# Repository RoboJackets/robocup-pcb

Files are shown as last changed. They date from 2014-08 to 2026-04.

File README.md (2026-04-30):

RoboCup PCB Repository
===========
Welcome to the Georgia Tech RoboJackets repository for management and storage of RoboCup's hardware files! Additional information about the team and current projects can be found on the [RoboJackets Website](http://www.robojackets.org/teams/robocup/) and the [RoboJacket Wiki](http://wiki.robojackets.org/w/RoboCup).

If you are a new member to the RoboCup electrical team and have never used *[git version control](http://git-scm.com/)* before, we highly recommend that you familiarize yourself with it by reading [this guide](https://git-scm.com/book/en/v2).

## Prerequisites
- A computer configured with git [[Linux (Preferred)](https://git-scm.com/install/linux)] [[Windows](https://windows.github.com)] [[Mac](https://mac.github.com/)]
- An installation of [KiCAD v10.0](http://kicad-pcb.org/download/)

## Setup

### Cloning the Repository
To clone the repository, run the following command in your terminal:
```
git clone git@github.com:RoboJackets/robocup-pcb.git
```

## Board Archives
All currently deployed boards as of 2026 were designed using KiCAD.

However, older boards in the archives were designed using [EAGLE](http://www.cadsoftusa.com/) or [PCB](http://pcb.geda-project.org) (a program that is part of the [gEDA project](http://www.geda-project.org))

Unfortunately, EAGLE and PCB are no longer supported by their respective companies, and are not available for download. If you need access to these files, you are on your own.

## License

This project is licensed under the Apache License v2.0.  See the [LICENSE](LICENSE) file for more information.

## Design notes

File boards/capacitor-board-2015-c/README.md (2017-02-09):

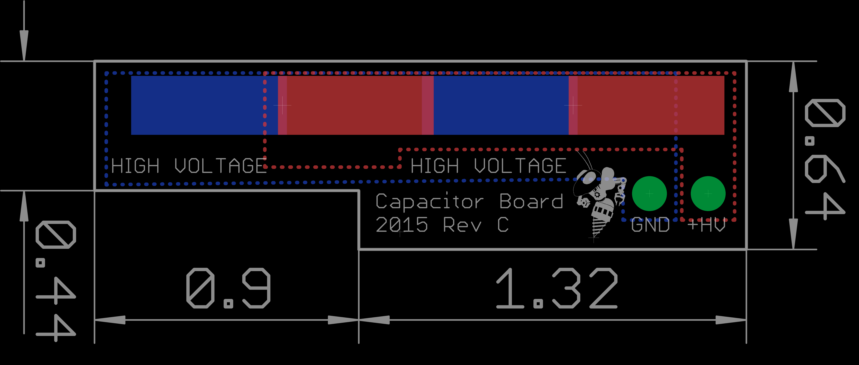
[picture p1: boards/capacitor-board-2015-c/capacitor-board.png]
Capacitor Board


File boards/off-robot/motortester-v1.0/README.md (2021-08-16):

# MotorTester Board
Off Robot Board

# Objective 
Simulate a 3 Phase Brushless Motor to connect to the control board, allowing us to test the motor functionality without blowing the motor. 

# Details 
- ATMega writes Hall sensor values (H1, H2, and H3) to the control board, which in turn responds with the proper voltages to the motor tester.  
- Voltages provided by the control board, either high (~18V), low (~0V) or float(somewhere in between), are stepped down by way of a voltage divider and the divided voltage is read in by the ATMega.  
- For each voltage, the ATMega checks to verify that it is correct, whether high, low, or float, for the given hall sensors, as given for the following table. 
 
## Hall Value/Voltage Level: 
001:10/  
101:1/0  
100:/10  
110:01/  
010:0/1  
011:/01  
These comparisons are made, and the LCD screen tells us if the motor is being supplied appropriately, to ensure it won't be blown.  

## PNG 
motortester

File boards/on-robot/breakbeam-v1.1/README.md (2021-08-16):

# Breakbeam Board
On Robot Board 

## Objective 
To indicate whether ball has been successfully captured by robot 

## Approach 
Infrared beam exists across the robot's mouth. Board detects whether the beam is broken by ball passing through it. Interfaces with kicker board. 

## PNG 
breakbeam

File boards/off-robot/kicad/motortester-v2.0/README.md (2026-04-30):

# Motor Tester Board v2.0

This board serves as a proof of concept (PoC) for the design of control board v4.0

## Components

The main components contained in this board are:

- Xilinx Spartan 7 25T FPGA
- QSPI Flash Memory
- CMOS Clock
- USB/JTAG/UART Interface
- 18.5V, 5V, 3.3V, 1.8V, 1.0V Voltage Levels
- 3 Phase Motor Driver

### FPGA

This is the main controller that coordinates the 5 different motor drivers.
It interfaces the main microcontroller via SPI and controls the 3 phase gate drivers.

The CMOS clock is connected directly to the FPGA as the sys_clk.

### QSPI Flash Memory

Non-volatile memory to store the config files for the FPGA. FPGA should be bootable from flash on reset.

### USB Interface

Allows to program the FPGA and QSPI Flash without the need of a debug probe. This is done using Xilinv Vivado.

### Voltage Levels

The FPGA board allows for different voltage levels on each IO Bank.

- The FPGA logic fabric uses 1.0V
- IOBANKs use 3.3V

Aside from the FPGA, the motor drivers require direct battery voltage, 18.5V (nominal) for the
motor current, and 5V to operate the gate driver IC.

The microcontroller also requires a 5V supply to be powered.

### Motor Driver

This is a 3 Phase BLDC motor driver.
(I'll list down the specifics of this later).

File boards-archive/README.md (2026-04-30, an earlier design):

# Boards Archive

A large reorganization of this repository was performed in early 2026. All such boards live (mostly unorganized) in the `pre-2026` directory. All other boards are organized by design revision (e.g. `rev-2027`).

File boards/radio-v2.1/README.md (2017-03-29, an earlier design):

# Radio Board

Board containing radio circuitry to communicate between robot(s) and base station

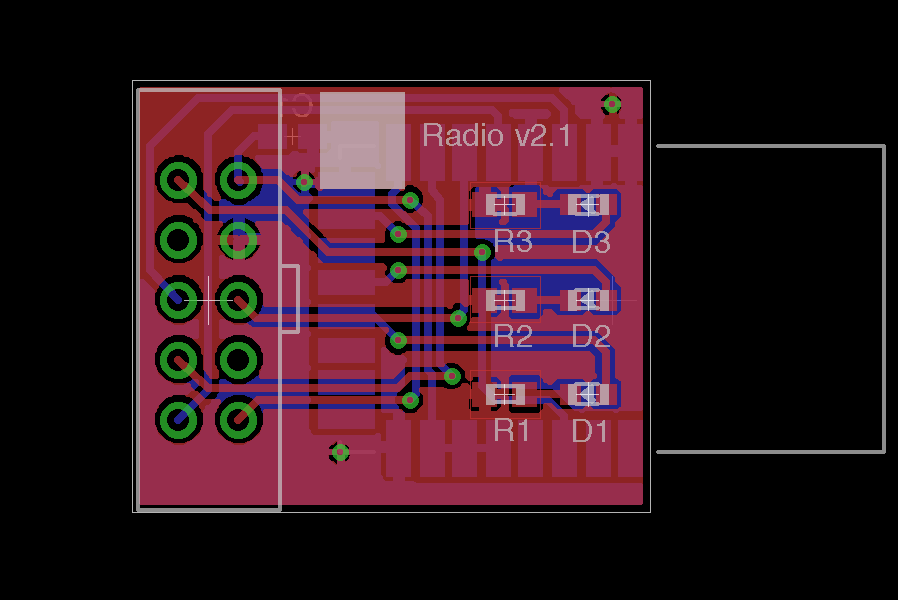
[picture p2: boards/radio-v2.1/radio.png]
Radio Board


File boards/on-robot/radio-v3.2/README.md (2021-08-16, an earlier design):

# Radio Board
On Robot Board 

# Objective
Uses onboard bluetooth/wifi module to communicate with other robots. Most radio logic is handled on the chip. 

# Approach 
- Radio outputs are delivered to the connector, which allows the robot to interface with this board.  
- Radio is supplied by a 3.3V source. DC-DC converter is used to step down the 5V supply on the board to the needed 3.3V volts, and keep power supply stable.  
- RF components are very sensitive, ESD protection chips are needed to prevent damaging components with any built up static.  
- The radio firmware may need updates. In event of update, there is a JTAG programming port.  

## PNG 
radio

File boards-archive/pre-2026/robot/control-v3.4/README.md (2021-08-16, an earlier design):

# Control Board
On Robot Board 

## Objective 
Regulates voltages, connects mTrain to other boards, user interface, hardware to enable motor control 

## Specifics of v3.4
IR connector, extra SPI connector, many improvements to be made

## Approach 
 - MTrain is our microcontroller, has three SPI buses which tie it to the FPGA, the radio, and then all other devices. 
 - AnalogIn is used to monitor battery voltage and input voltage  
 - Reset network reset MTrain if the 3.3V is low and the MTrain is high  
 - IO expander connects hex pins and DIP switches to MTrain for inputs into MTrain
 - FPGA handles all of the wheel drivers and the dribble driver, including the SPI interface to those motor drivers (AUX)
 - Handles hall sensors and writing three phase motor states.

- The battery provides 18.5V, so the voltage regulation circuits also produce other voltage levels (5V and 3.3V) that other devices run off.
- 18.5V is only needed for the motors.  
- There are also 1.2V and 2.5V lines, and when these are out of tolerance, error LEDs are activated

- Wheel Drive Module writes each of the three phases for the motor. Takes inputs of whether phase should be high and low, and uses outputs to write each phase
- Phase is set that it can be high (shorted to 18V) low (shorted to ground) or float (some indeterminate phase in between).
- Dribbler Drive Module works in similar approach

## Control board has connectors for all of the different modules on the board, including:
- IMU  
- Kicker  
- Radio  
- Ball Speed (IR)  
- I2C Module  
The SPI interfaces for each of these connectors is supplied by the MTrain and monitored by the Dot Star network

## PNG 
control

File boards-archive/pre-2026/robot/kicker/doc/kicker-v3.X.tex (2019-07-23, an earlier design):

\documentclass[12pt, letterpaper]{article}
\usepackage[utf8]{inputenc}
 
\title{RoboJackets RoboCup Kicker v3.0}
\author{William Stuckey \thanks{I'd like to acknowledge Ryo Osawa and Jon Jones for their patient mentorship in helping a CS major through the world of analog and digital electronics for the first time.}}
\date{August 2018}
 
\begin{document}
 
\begin{titlepage}
\maketitle
\end{titlepage}

\section{Preface}

I want to write this document to address the recurring pattern of shoddy RoboCup kicker boards. Electrical Engineers with practical experience are pretty hard to come by, especially early in their undergraduate careers. For many kicker boards designers, this is their first time doing \"serious and practical\" EE work (myself included). A lot of past mistakes are undocumented or have been ignored. Over the past month I've looked at every kicker revision since 2013 and talked to past members in an attempt to understand common mistakes. \textbf{Future kicker board designers should start here.} At least that is my hope.

\section{Introduction}

In RoboCup SSL, ground kicks (referred to as kicks) and chip kicks (referred to as chips) are critical robot functions. In order to get precise control over kick speed, the league has largely standardized on using elctromagnetic solenoids to kick and chip balls. By varying the amount of time current flows through the solenoid, software can control how hard the ball is kicked. 

In order to support this system of ball control, the robot needs a subsystem to drive these solenoids. The subsystem in contained on the kicker board, a PCB dedicated to this task. The highest level functional overview contains three main systems: 1) a charging system to convert low voltage DC to high voltage DC that charges a capacitor bank; 2) a discharge system to release the energy stored in the capacitor bank through the solenoids, thus kicking the ball; 3) a control system to regulate charge and discharge cycles accurately and safely. Subsystems for v3.0 are described in detail below as subsections under \"Kicker v3.0\".

Driving a solenoid with sufficient force has proven to be a non-trivial task for the following reasons: 1) modeling the solenoid impedance over time is difficult because mesauring the magnetic field is difficult; 2) modeling energy transfer to the mechanical system is difficult to measure; 3) high voltages and currents are involved making some mistakes far more fatal than digital designers are used to. Points 1 and 2 result in a lot of design iteration based on testing and high-level data gathering rather than theory. The third point results in usually ignorable issues, no longer being ignorable. This includes noise, ringing, and transient voltage spikes. As well, FET and diode ratings have added complexity in voltage ratings and swithing times. Read data sheets for AC subsystem components carefully. 

As a final note, the energy stored in the capacitor bank is non-trivial. It can and will shock you, and under very ideal conditions is potentially dangerous. Just be careful when handling these boards.

\section{Past Results}
Past kicker board designs have had mixed success in terms of safety and reliability. A short list of results is below:

\subsection{Kicker 2013}
We don't have a lot of surviving experiential notes and docs from the 2013 era. The boards weren't radcally different. They had a smaller storage capacity and less debugging information. We've also been handed down the criticisms that they didn't like the choice of IGBTs over power FETs for discharge because the switching times would be too high if they ever wanted to PWM control the solenoids. The cost was also higher. 

Some older designs also use two stacked IGBTs/FETs to achieve a high current rating. The failure rate was too high due to swithing time variances from (relatively) imprecise binning. 

\subsection{Kicker 2015 (v1.X)}
The 2015 kicker suffered from two fatal issues. The first issue was the gate voltage rating of AC system switching fet. The gate was only rated for 20V and was driven directly from the battery. While a 5 cell LiPo has a nominal voltage below 20V, at max charge and no load the LiPo will have a voltage of about 21V. Over time this damaged FET gates and caused the HVAC system to fail.

Additionally, the microcontroller used to regulate chrage and discharge cycles was located too far to close to the HVAC transformer. The interference prevented communication between the microcontroller and the surrounding components rendering it useless. We had to tap the relevant lines with wire and assert control signals from elsewhere in 2015. This impacted performance.

\subsection{Kicker 2017 (v2.X)}
The 2017 kicker design addressed issues from the 2015 design. 

Initially the 2017 design had a misspeced rectifer diode on the HVAC system. The Trr (reverse recovery time) was too long, causing almost all of the energy to be attenuated by the diode or reflected back to the switching FET. This was further complicated by the fact that the diodes varied greatly in binning. Some well binned diodes had an acceptable Trr which result in it taking over a year to identify the issue. Once the part was speced correctly the charging system worked very well.

Early on we had difficulty kicking at low speeds because of generated interference. We determined the cause of the issue was the presence of TVS diodes on the discharge FETs. They were originally intended to prevent the 21V max battery from damaging a 20V rated gate, but the breakdown threshold and parasitic capcitance resulted in oscillation that rapidly switched the discharge FET on and off generating massive amounts of high frewuency interference. This caused microcontroller reboots and corrupted data on the global SPI line resulting in radio brownouts. This was not truely fixed on 2017, instead the TVS diodes were simply removed at the 21V rarely damaged the power FETs. In v3.0, a 15.0V LDO is used to drive the FETs rather than direct batter voltage. The 20V TVS diodes remain in the design to protect the FETs against ringing and trasient spikes. 

Another minor issue observed under unclear condtions was the presence of ringing on the HVAC regulator IC control lines. It was difficult to assertain the magnitude of the issue, as the parasitic inductance and capcaitance of scope probes amplified the problem. As a precaution, snubbers with a cutoff frequency of 1kHz have been added to all HVAC regulator IC control lines. These are some of the longest traces on the board and the only digitial IO lines that are required to pass by the HVAC system.

The last minor issue observed was inconsistency in HV charge time and level holding. The deathlight, intended to indicate if there is power on the HV rail leaked too much current. We think replacing this with a microcontroller controlled level indiciator is an acceptable trade off. It now requires the microcontroller to function to report voltage on the line. Our operating assumption is that if it's too broken to report voltage level it's also too broken to flag a charge cycle. When unplugged, the auto discharge light will come one and it's approximate margnitude of brightness will indicate remainig charge ensuring that in virtually any case where the HV rail is powered, some safety indicator will be on. The leakage through the microcontroller should now be ones to tens of microamps rather than tens of miliamps. The inconsistency is auto-discharge time and cutoff was also likely a binning issue. We are reducing the tolerance when practical to 1\% or 0.1\% to address these issues.  

The biggest area for improvement on 2017 was the HV leakage issue and charge time. Most boards still took 2.5-3.5+ seconds to charge make our repetitive kick rate low. We are attempting to boost the charge rate in v3.0 to around half second. 

\section{Kicker v3.X}  
Kicker v3.0 began design in summer of 2018. As of now, it is under design review. The following seubsections are intended to be highly techinical, describing why parts were speced the way they were and what higher level considerations were included. 

\subsection{Overview}

\subsection{Input Power}
The input power section is responsible for generating the necessary sources of power for the board. It also includes protected. In this kicker board we need 4 voltages: raw battery, 15V, 5V, and HV. The source of HV has a dedicated section below called High Voltage Charging.

\subsubsection{Changes in v3.X}
A few changes were made to the input power subsystem. First, the surface mount fuse was replaced with a socketed fuse. This board will likely be able to charge at a very high rate and surface mount fuses become impractical at 50A. It may also be required to lower the charging current so easily swapping the fuse is good.

A new feature is the addition of reverse polarity pretection. This is done with a PFET right after the fuse. Although the input connector is polarity protected, in the past we've still managed to mess it up on occasion. When this happes 10 hours of labor and \$150 in parts are lost. Adding the protection is cheap and easy and will save time when accidents happen.

A new 15V rail was added to prevent overvoltages on discharge FET gates. The 15V rail is sourced from an adjustable LDO. 

TVS diodes were added to every power rail, except HV, to protect regulation and digital circuitry.

\subsection{Microcontroller}
The microcontroller is the primary logic for the kicker board. It communicates with the control board to report charge level, kick cycles status, readiness, and errors. It also has the critical function of translating a kick/chip strength into a time interval to control kick speed. It commands the charge and discharge states, ensure they've never occur at the same time. The microcontroller is also responsible for for handing breakbeam information.

\subsubsection{Changes in v3.0}
The microcontroller was upgraded from an ATTiny167 to an ATMega32. We wanted additional IO, timing features, and flash space. It's very similar to the 167 most ways just with an extra IO bank and flash. We considered switching to ARM, but liked that the 32 could be flashed from the same pins as it being a SPI slave, so we can flash and then communcate with the chip over the same SPI lines. It also meant we wouldn't have to rewrite significant chunks of the code base. The extra IO was used for error reporting.

$$ \omega_\mathrm{desired\_cutoff} \approx 10 kHz $$

\begin{equation} \label{eq:rc_snub}
\omega_\mathrm{cutoff} = 1 / (2 * \pi * R * C)
\end{equation}

$$ R_\mathrm{chosen} = 160 \Omega, C_\mathrm{chosen} = 0.1 \mu F $$

\begin{equation} \label{eq:rc_snub_situ}
\omega_\mathrm{cutoff} = 1 / (2 * \pi * 160 * 0.0000001) \approx 9947.18 Hz, \epsilon \approx 0.005
\end{equation}

RC snubbers were added to IO lines that pass by the HVAC system. This is included as a precaution based on past observed behavior that may case IO errors due to voltage spikes from interferences. These IO lines don't see high frequency switching so we can play pretty fast and loose on the snubber calibaration. We've picked an initial cutoff frequency of 10kHz. The cutoff frequency of an RC snubber can be calculated using the equation \ref{eq:rc_snub}. We selected resistor and capacitor values that can easily be acquired in E96 and the resulting cutoff frequency and error from desired can be seen in equation \ref{eq:rc_snub_situ}.

\subsection{High Voltage Charging}
The high voltage charging systems works by switching low voltage DC into low voltage AC. This low voltage AC becomes the primary side input to a transformer, that produces a higer voltage AC. We use a transformer with a turns ratio of 10:1, so we get a voltage approximately 10 times higher. The regulator actually produces a slightly higher voltage. The high voltage AC (HVAC) is then rectified by a diode in to high voltage DC to be store in the capacitors. 

Import considerations are the current ratings of the switching FET, transformer, and rectifier diode. The datasheet of you switching regulator IC can usually help you spec these components. For the diode, take extra caution to ensure the recovery times meet spec based on the swithing frequency of your regulator IC. For many ICs, that frequency is configurable.

\subsubsection{Changes in v3.0}
Significant changes were made to the HVAC system. The swithcing IC was changed from the LT3757 to the LT3751. The 3757 is a generic regulator, but the 3751 is specifically made for charging capacitor banks and other appllications that have periodic rather than coninuous charging cycles. Rather than enabling charging, a rising edge flags a charge cycle and the chip will carry out the cycle until a target voltage is reached or a fault occurs. The primary battery rail bypass capitance was increased to 1000uF of electrolytic and 30uF ceramic to accomodate the greater demands and interference of a 50A charging circuit. These values were recommended by the LT3751 datasheet.

The HVAC system has been updraded to support a primary current draw of 50A. The recitifier diode was respeced to have have a lower Trr and higher current (5A) to support faster charge times. The transformer was respeced from within the same product line as well. The DA203X series was replaced with the GA43XX series. The new transformer supports a maximum primary current of 50A rather than 10A. The turn ratio is unchanged at 10:1. The switching FET was already withing spec, and not changed. 

The capacitor bank was respeced as the old caps had been discontinued. We now have slightly larger (both physically and in capacitance) caps, bringing the total capacitance of the bank to 4000uF, a ~25\% increase.

The 5V swiitch mode regulator bypass caps were changed to better support how the global marked now produces ceramics. The pads were largened and duplicated to give the maximum flexibility in being able to source parts from the market.

\subsubsection{LT3751 Part Spec}
The HV\_AC regulator is the most complicated subsystem on the board and also one the hardest to debug. Rapid switching and high currents present a noise filled measurement challenge for most hobbiest equipment and complex analog interactions can make finidng the source of obvious failures hard. Subtle failures are even harder to debug because often times insturmentation is not recording when stochastic errors occur that wear down a part slowly over time. In order to help future designers, we are going to cover how we speced every part of the HV\_AC subsystem and what part attributes are the most important. If you haven't acquired a copy of the LT3751 datasheet, now would be the time to do so.

\paragraph{Voltage Protection Lockouts}

Before calibrating the voltage lockouts, we need to determine what an acceptable voltage range should be. In order to do this, we need to understand what the safe operating limits of our battery are and what other protection mechanisms we have put in place.

We define the acceptable LiPo cell voltage not underload as 

$$ 3.4 V < V_\mathrm{cell} < 4.2 V $$

and the acceptable minimum for a cell under load as

$$ V_\mathrm{cell\_load} \ge 3.1 V $$

Additionally we clamp $ V_\mathrm{batt} $ at 22.2V using a TVS diode.

With this information in hand, we can calculate our voltage lockouts from the following constraints

$$ N = 5, the number of cells $$
$$ V_\mathrm{cell\_abs\_min} = 3.1 V $$
$$ V_\mathrm{batt\_abs\_min} = N * V_\mathrm{cell\_abs\_min} = 5 * 3.1 V = 15.5 V $$
$$ V_\mathrm{batt\_abs\_max} = 23.5 V $$

\begin{equation} \label{eq:vbatt_range}
V_\mathrm{batt\_abs\_min} < V_\mathrm{batt} < V_\mathrm{batt\_abs\_max} \equiv 15.5 V < V_\mathrm{batt} < 23.5 V
\end{equation}

With the acceptable voltage range deifined, we can now calibrate our lockouts. Both Over Voltage and Under Voltage Lock Outs, OVLO and UVLO respectively, are defined by equation \ref{eq:lt_vlos}, which is arranged to provide the resistor value for convenience in equation \ref{eq:lt_vlos_arr}. 

\begin{equation} \label{eq:lt_vlos}
V_\mathrm{LO} = 1.225 + 0.50 \mu A * R_\mathrm{LO\_CALIB}
\end{equation}

\begin{equation} \label{eq:lt_vlos_arr}
R_\mathrm{LO\_CALIB} = (V_\mathrm{LO} - 1.225) / 0.5 \mu A
\end{equation}

Substituting the values from the range defined in equation \ref{eq:vbatt_range} into equation \ref{eq:lt_vlos_arr} yields the following resistor values:

$$ R_\mathrm{lvlo} = 285500 \approx 287k (E96) $$
$$ R_\mathrm{ovlo} = 445500 \approx 442k (E96) $$

\paragraph{High-Level Charding Characterization}

\subsection{High Voltage Discharging}

\subsubsection{Changes in v3.0}

\subsection{High Voltage Auto Safe Discharge}

\subsubsection{Changes in v3.0}

\subsection{Breakbeam}

\subsubsection{Changes in v3.0}

\subsection{Debugging and Status}

\subsubsection{Changes in v3.0}

\subsection{Errata}
None yet.

\end{document}

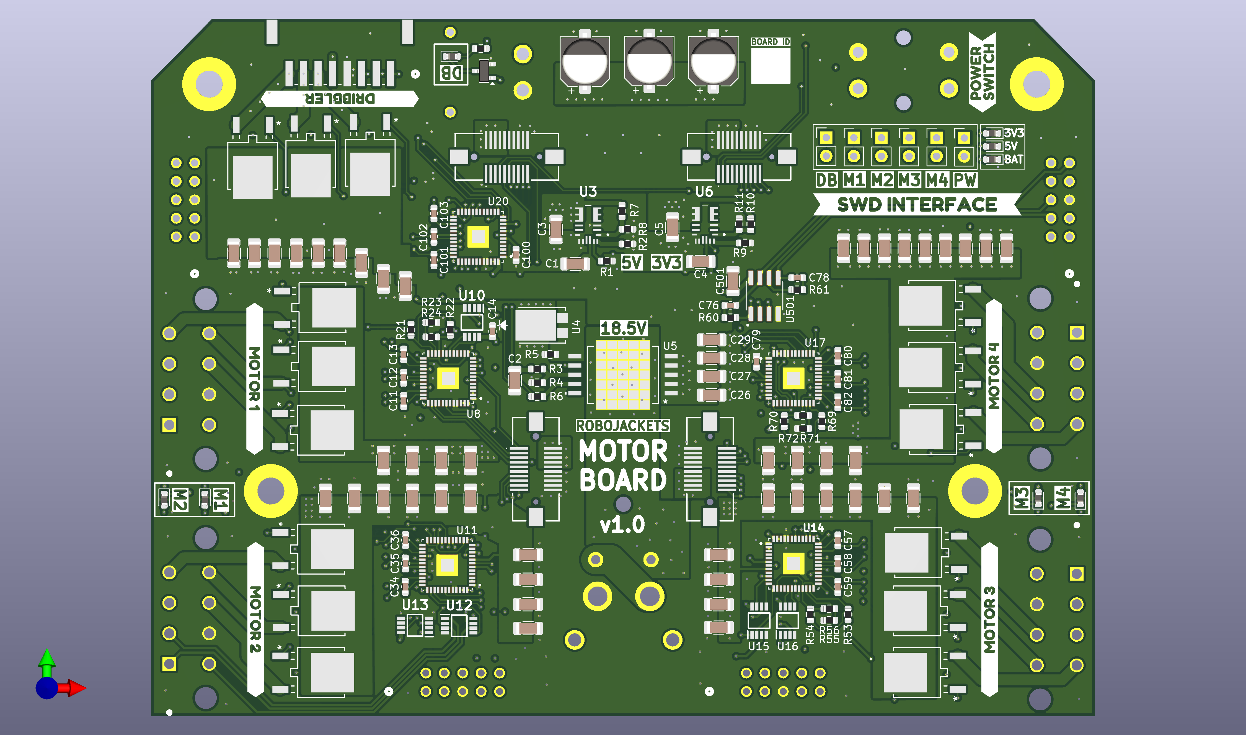
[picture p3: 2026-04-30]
boards/rev-2026/motorboard-v1.0/images/motorboard-modelpng.png

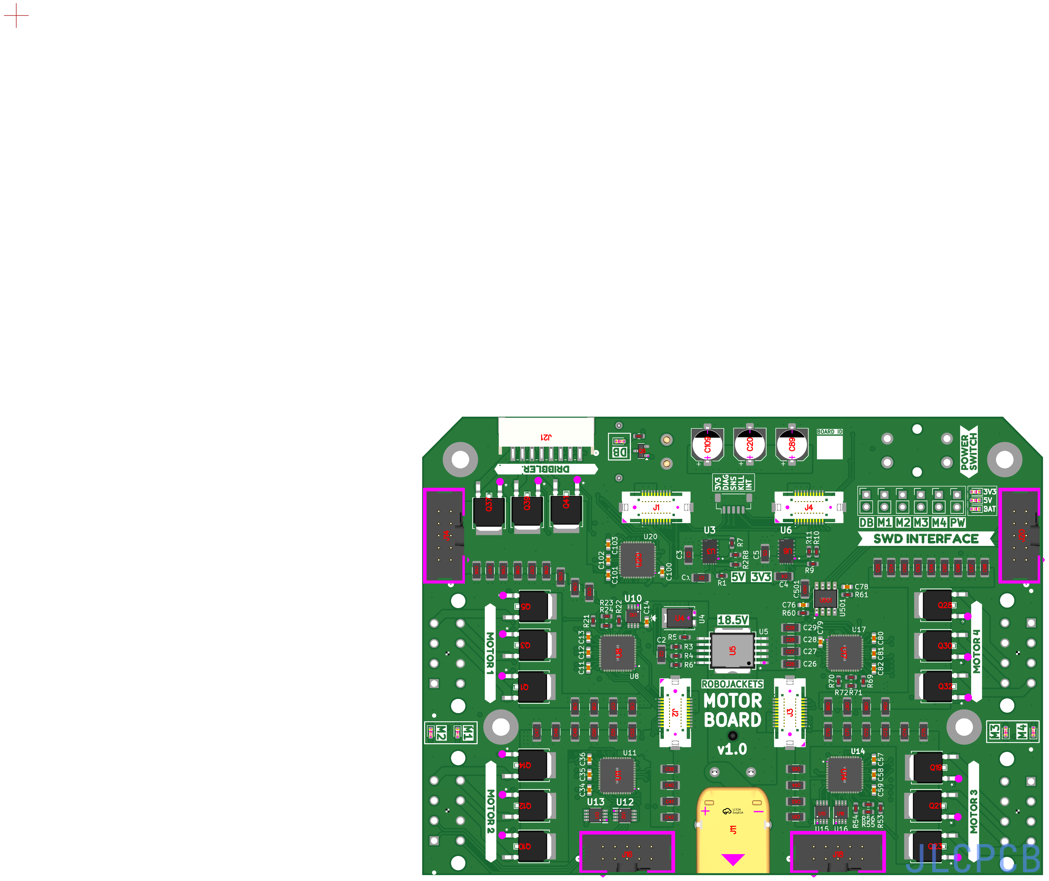
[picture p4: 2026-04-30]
boards/rev-2026/motorboard-v1.0/images/top_placement.png

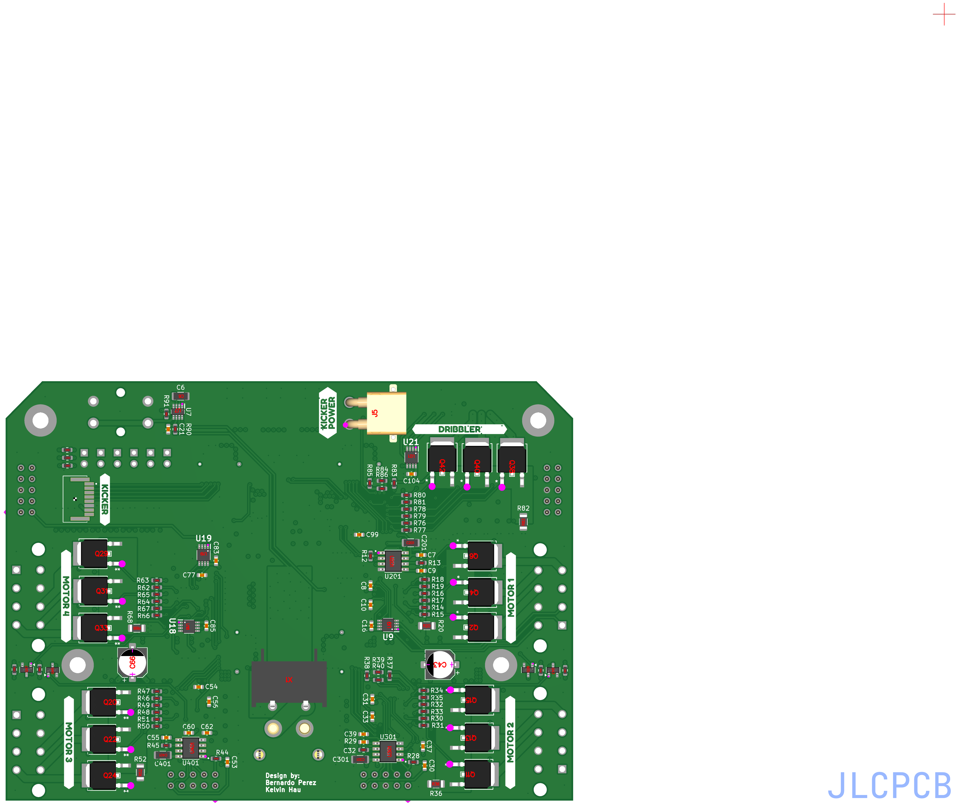
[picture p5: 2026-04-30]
boards/rev-2026/motorboard-v1.0/images/bottom_placement.png

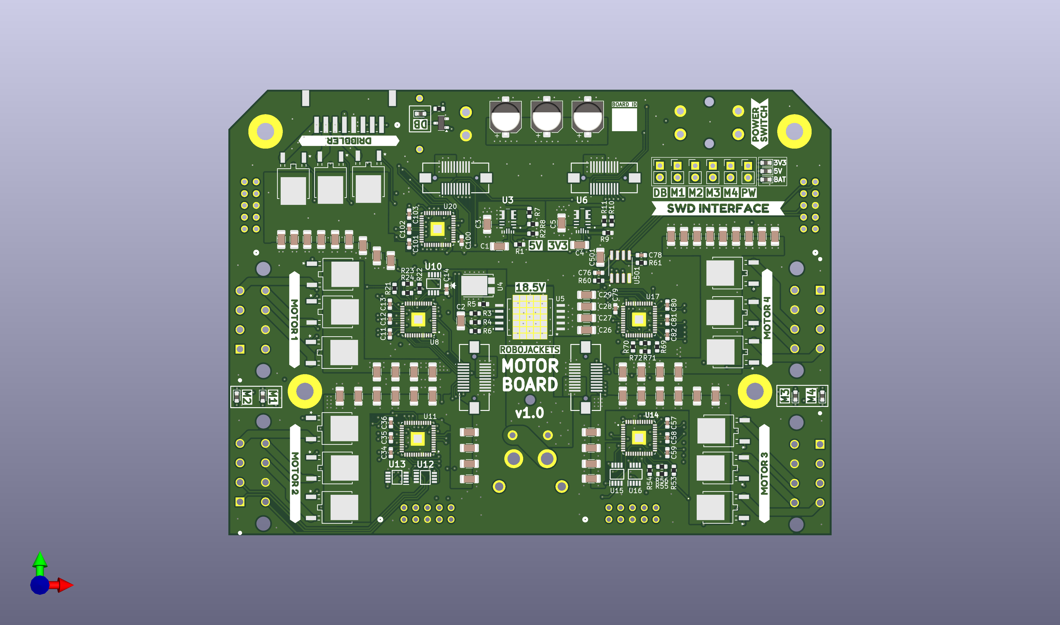
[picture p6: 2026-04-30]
boards/rev-2026/motorboard-v1.0/images/motorboard-model.png

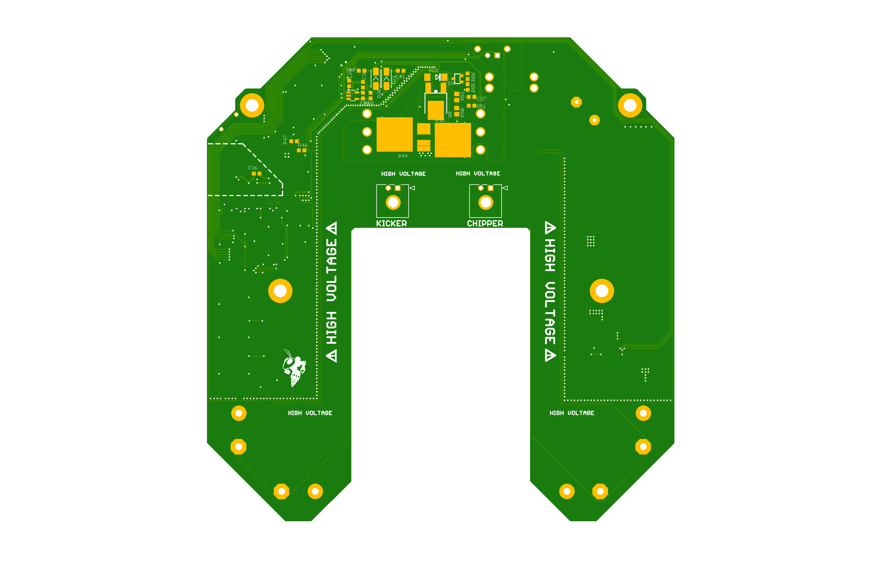
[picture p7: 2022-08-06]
boards/on-robot/kicker-4.0/kicker2.png

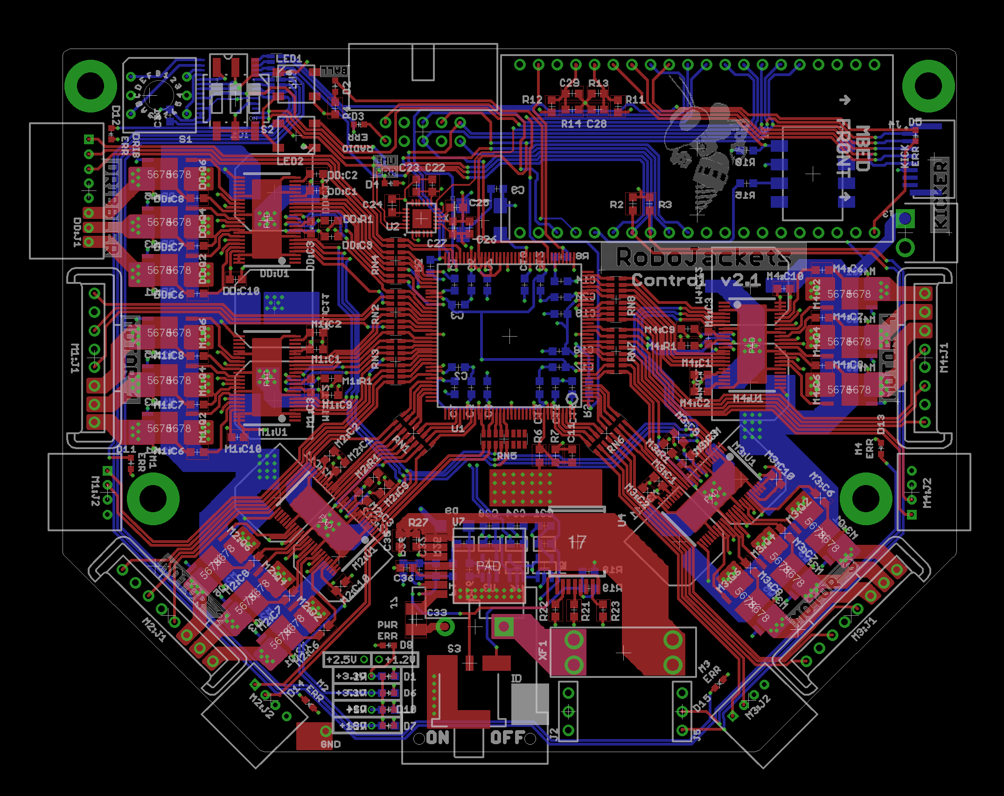
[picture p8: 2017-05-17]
boards/control-v2.1/control.png

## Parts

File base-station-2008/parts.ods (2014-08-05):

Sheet: Parts List
Type | Value | Package | Amount | P/N
SMD Resistor | 10 | R0603 | 2
SMD Resistor | 220 | R0603 | 5
SMD Cap | .1uF | C0603 | 2
SMD Cap | 10uf | PANASONIC_B | 1
SMD Cap | 10uf | C1206 | 1
SMD Cap | 1uF | C0603 | 5
SMD Resistor | 4.7k | R0603 | 1
SMD Cap | 47uF | PANASONIC_E | 1
Linear Vreg | 7805T | TO220H | 1 | LM7805CT
Microcontroller | ATMEGA169-16A | TQFP64 | 1 | ATMEGA169-16A | ATMEGA169V-8MU-ND | sample
LED |  | LED5MM | 5
Level Converter | MAX232-SO16 | SO16 | 1 | MAX232NSR | 296-15895-1-ND
Oscillator | 14.7456MHz | 7X5MM | 1 | CSX750FCC14.745600M-UT | 300-7209-1-ND | waiting
Ant. Conn |  | RPSMA_TH | 2
Receiver |  |  | 1 | RXM-900-HP3
Transmitter |  |  | 1 | TXM-900-HP3
Connector | JST_PA_2 | JST_PA_2 | 2
Connector | JST_PA_4 | JST_PA_4 | 1
SPI Conn | 2X05 | pinhead | 1

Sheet: Sheet1
Part | Value | Package | Library | Amount
R3 | 10 | R0603 | rcl
R4 | 10 | R0603 | rcl
R2 | 200 | R0603 | rcl
R5 | 200 | R0603 | rcl
R6 | 200 | R0603 | rcl
R7 | 200 | R0603 | rcl
R8 | 200 | R0603 | rcl
C3 | .1uFl | C0603 | rcl
C4 | 10uf | PANASONIC_B | rcl
C5 | 10uf | C1206 | rcl
C10 | 1uF | C0603 | rcl
C6 | 1uF | C0603 | rcl
C7 | 1uF | C0603 | rcl
C8 | 1uF | C0603 | rcl
C9 | 1uF | C0603 | rcl
JP1 | 2X05 | pinhead | (24.62
R1 | 4.7k | R0603 | rcl
C1 | 47uF | PANASONIC_E | rcl
IC2 | 7805T | TO220H | linear
IC3 | ATMEGA169-16A | TQFP64 | avr
C2 | C1206 | rcl | (65.95
U$1 | JST_PA_2 | JST_PA_2 | jst_pa
U$2 | JST_PA_2 | JST_PA_2 | jst_pa
U$8 | JST_PA_4 | JST_PA_4 | jst_pa
LED2 | LED5MM | led | (31.53
LED3 | LED5MM | led | (50.06
LED4 | LED5MM | led | (50.1
LED5 | LED5MM | led | (57.44
LED6 | LED5MM | led | (57.48
U$9 | MAX232-SO16 | SO16 | max232
U$3 | OSCILLATOR | 7X5MM | misc-personal
U$6 | RP_SMA_TH | RPSMA_TH | linx
U$7 | RP_SMA_TH | RPSMA_TH | linx
U$4 | RXM-900-HP3 | RXM-900-HP3 | HP3
U$5 | TXM-900-HP3 | TXM-900-HP3 | HP3

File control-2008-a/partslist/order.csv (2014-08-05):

Value | Device | Package | Count | Digikey # | Quant On Hand | Quant to Order | Notes
Green | LEDCHIP-LED0603 | CHIP-LED0603 | 2 | 160-1183-1-ND | 15 | 20
Yel |  |  | 2 | 160-1180-1-ND | 15 | 20
Red |  |  | 2 | 160-1182-1-ND | 15 | 20
 | JP2E | JP2 | 2 | S1012E-36-ND | 0 | 3
BAS16H | DIODE-SOD323-W | SOD323-W | 1 | BAS16HT1GOSCT-ND | 0 | 10 | Dboost
 | NMOSSOT23 | SOT-23 | 1 |  | 0 |  | Phillip's FET
0.01uF | C-USC0603 | C0603 | 6 | 399-1082-1-ND | 10 |  | 10000pf = .01uf
0.1uF | C-USC0603 | C0603 | 30 | 399-1100-1-ND | 500 | 0
10 | R-US_R0603 | R0603 | 2 | RHM10GCT-ND | 10
100pF | C-USC0603 | C0603 | 4 | 399-1061-1-ND | 10
10K | R-US_R0603 | R0603 | 2 | RHM10KGTR-ND | 10 |  | NOT ORDERED
10uF | C-USC1206 | C1206 | 3 | PCC2233CT-ND | 10
1K | R-US_R0603 | R0603 | 2 | RHM1.0KGCT-ND | 10
1uF | C-USC0603 | C0603 | 6 | PCC2399CT-ND | 0
220 | R-US_R0603 | R0603 | 48 | P220GCT-ND | 200
2M1-DP1-T1-B1-M2QE | 2M1-DP1-T1-B1-M2QE | 2M-DP-M2 | 1 | 432-1171-ND | 6 |  | Power switch
30.9K | R-US_R0603 | R0603 | 1 | 541-30.9KHCT-ND | 0
3522 | 3522 | 3522 | 2 | 3522K-ND | 0 |  | Fuseholders – 2 pcs
4.7K | R-US_R0603 | R0603 | 37 | RHM4.7KGCT-ND | 200
40K | R-US_R0603 | R0603 | 1 | RHM40.2KHCT-ND | 10
470 | R-US_R0603 | R0603 | 1 | RHM470GCT-ND | 0
470uF | CPOL-USE | PANASONIC_E | 16 | PCE3892CT-ND | 0
ADP1711-1.2 | ADP1711-1.2 | SOT23-5 | 1 | ADP1711AUJZ-1.2-R7CT-ND | 0 |  | 1V2 regulator
BAS16XV2 | BAS16XV2 | SOD-523 | 15 | BAS16XV2T1GOSCT-ND | 100 |  | Hall diodes
FH_11_H | FH_11_H | FH_11_HOR | 4 | HFB11CT-ND |  |  | Motor Connector
HP3_RX_SIP | HP3_RX_SIP | RX_DIP | 1 | RXM-900-HP3-PPS-ND |  |  | Do we want to order new modules?
HP3_TX_SIP | HP3_TX_SIP | TX_DIP | 1 | TXM-900-HP3-PPS-ND |  |  | Do we want to order new modules?
JST_PA_6 | JST_PA_6 | JST_PA_6 | 4 | 455-1821-ND | 10 |  | Header – actually only 4 per board (alt motors)
 |  |  | 4 | 455-1490-ND | 10 |  | Housing
JST_PA_8 | JST_PA_8 | JST_PA_8 | 2 | 455-1823-ND | 10 |  | Header
 |  |  | 2 | 455-1492-ND | 10 |  | Housing
 |  |  |  | 455-1325-1-ND | 100 |  | PA Pins
JST_VH_2 | JST_VH_2 | JST_VH_2 | 2 | 455-1639-ND | 20 |  | Header
 |  |  |  | 455-1183-ND | 20 |  | Housing
 |  |  |  | 455-1319-1-ND | 20 |  | VH Pins
LM2734Y | LM2734 | SOT23-6L | 1 | LM2734YMKCT-ND | 0
LP2985-18 | LP2985-18 | SOT23-5 | 1 | 296-18474-1-ND | 0
LP2985-25 | LP2985-25 | SOT23-5 | 1 | LP2985IM5-2.5CT-ND | 0
LPC2102 | LPC2102 | TQFP48 | 1 | 568-2094-ND | 0
MBR120LSF | DIODE-SOD123 | SOD123 | 2 | MBR120LSFT1GOSCT-ND | 0
MMBTA06LT1 | BC848 | SOT23 | 1 | MMBTA06LT1GOSCT-ND | 0
NTMS4503N | NTMS4503N | SO8 | 15 | IRF7805APBFCT-ND | 95 |  | NFET – IRF7805A
OSC | OSC | XTAL_LCC | 1 | 535-9311-1-ND | 0
PAN_EV_SWITCH | PAN_EV_SWITCH | PAN5 | 2 | P12240SCT-ND | 0
PS12 | PS12 | PS12 | 1 | 445-2525-1-ND | 6 |  | Buzzer
RP_SMA_TH | RP_SMA_TH | RPSMA_TH | 1 | CONREVSMA001-ND | 0
SWS004 | SWS004 | SMS-004 | 1 | CT2194MST-ND | 0 |  | Dip Switch
TC4428 | TC4428 | SO08 | 15 | TC4428COA-ND | 100
UPG2214 | UPG2214 | SMINI-6 | 1 | UPG2214TK-A-ND | 0
XC3S_TQ144 | XC3S_TQ144 | TQFP144 | 1 | 122-1478-ND | 0
 |  |  |  |  |  |  | Tweezers
 |  |  |  |  |  |  | Solder
M25P10 | M25P10 | SO08 | 1 | 511-M25P10-AVMN6P | 0 |  | FLASH – Mouser
NTMS10P02R2 | NTMS10P02R2 | SO8 | 15 | 512-FDS6673BZ | 35 |  | PFET – Mouser
MSS7341 | MSS7341 | MSS7341 | 1 |  | 10 |  | Sampled from coilcraft

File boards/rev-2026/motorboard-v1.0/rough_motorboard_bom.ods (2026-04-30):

Reference | Value | Datasheet | Footprint | Qty | DNP | Approx Unit Cost | Total Cost Per Board | Total Cost
C1,C2,C20,C31,C51,C52,C53,C54 | 0.1nF | ~ | Capacitor_SMD:C_0603_1608Metric | 8 |  | $0.40 | $3.20 | $32.00
C3,C6,C11,C13,C14,C15,C16,C17,C32,C34,C35,C36,C37,C38,C55,C57,C58,C59,C60,C61,C74,C76,C77,C78,C79,C80,C93,C95,C96,C97,C100 | 100nF | ~ | -- mixed values -- | 31 |  | $0.40 | $12.40 | $124.00
C4 | 400nF | ~ | Capacitor_SMD:C_1206_3216Metric | 1 |  | $0.40 | $0.40 | $4.00
C5 | 22nF | ~ | Capacitor_SMD:C_1206_3216Metric | 1 |  | $0.40 | $0.40 | $4.00
C7,C8,C18,C19,C21,C22,C23,C24,C25,C27,C29,C30,C39,C40,C41,C42,C45,C46,C47,C48,C49,C50,C62,C63,C64,C65,C68,C69,C70,C71,C72,C73,C81,C82,C83,C84,C87,C88,C89,C90,C91,C92,C99,C101,C102,C103,C106,C107,C108,C109,C110,C111 | 10uF | ~ | Capacitor_SMD:C_1206_3216Metric | 52 |  | $0.40 | $20.80 | $208.00
C9,C10 | 22uF | ~ | Capacitor_SMD:C_1206_3216Metric | 2 |  | $0.40 | $0.80 | $8.00
C12,C33,C56,C75,C94 | 1uF | ~ | Capacitor_SMD:C_0603_1608Metric | 5 |  | $0.40 | $2.00 | $20.00
C26,C28,C43,C44,C66,C67,C85,C86,C104,C105 | 220uF | ~ | Capacitor_THT:CP_Radial_D10.0mm_P5.00mm | 10 |  | $0.40 | $4.00 | $40.00
C98,C112,C113,C114,C115,C116,C117,C118,C119,C120 | 100n | ~ | Capacitor_SMD:C_1206_3216Metric | 10 |  | $0.40 | $4.00 | $40.00
D1,D2,D3,D4,D5,D6,D7,D8,D9,D10 | GREEN | ~ | Diode_SMD:D_0603_1608Metric | 10 |  | $0.20 | $2.00 | $20.00
F1 | Fuse | ~ |  | 1 |  | $0.30 | $0.30 | $3.00
J1 | XT60PW-M | https://www.tme.eu/Document/b13629717d44ae038681dba08d18c0b6/XT60PW-M.pdf | XT60PWM | 1 |  | $1.00 | $1.00 | $10.00
J2,J6,J10,J11,J14 | SWD | ~ | Connector_PinHeader_2.54mm:PinHeader_1x04_P2.54mm_Vertical | 5 |  | $1.00 | $5.00 | $50.00
J3,J4,J5,J7,J12 | 39301080 | 39301080 | RoboJackets-Connectors:CON_39301080 | 5 |  | $1.50 | $7.50 | $75.00
J8 | HFW8R-1STE1H1LF | https://cdn.amphenol-cs.com/media/wysiwyg/files/documentation/datasheet/flex/flexconnectors_100mm_hfw_r.pdf | RoboJackets-Connectors:AMPHENOL_HFW8R-1STE1H1LF | 1 |  | $0.30 | $0.30 | $3.00
J9 | XT60PW-F | https://www.tme.eu/Document/1191bc2fa3aee3c446e5a895fd8f7983/XT60PW-F.pdf | XT60PWF | 1 |  | $1.00 | $1.00 | $10.00
J13,J15 | Conn_01x12 | ~ |  | 2 |  | $0.50 | $1.00 | $10.00
J18,J19,J20,J21 | 52901-0274 | https://www.molex.com/pdm_docs/sd/529010274_sd.pdf | RoboJackets-Connectors:529010274 | 4 |  | $4.00 | $16.00 | $160.00
Q1,Q2,Q3,Q4,Q5,Q6,Q7,Q8,Q9,Q10,Q11,Q12,Q13,Q15,Q16,Q17,Q18,Q19,Q20,Q22,Q23,Q24,Q25,Q26,Q27,Q29,Q30,Q31,Q32,Q33 | STD140N6F7 | https://www.st.com/content/ccc/resource/technical/document/datasheet/group1/de/02/69/d9/32/b8/44/66/DM00257307/files/DM00257307.pdf/jcr:content/translations/e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 | DPAKTO-252_A2_STM | 30 |  | $2.00 | $60.00 | $600.00
Q14,Q21,Q28,Q34,Q? | BSS83P | http://www.farnell.com/datasheets/1835997.pdf | Package_TO_SOT_SMD:SOT-23 | 5 |  | $0.40 | $2.00 | $20.00
R1,R2,R28,R29,R42,R43,R44,R45 | 120 | ~ | Resistor_SMD:R_0603_1608Metric | 8 |  | $0.10 | $0.80 | $8.00
R3,R4,R5,R6,R7,R9,R24,R41,R57,R69,R81,R82,R83,R84,R85,R86,R87,R88,R89,R93,R94 | 10k | ~ | Resistor_SMD:R_0603_1608Metric | 21 |  | $0.10 | $2.10 | $21.00
R8,R22,R23,R39,R40,R55,R56,R67,R68,R79,R80 | 1k | ~ | Resistor_SMD:R_0603_1608Metric | 11 |  | $0.10 | $1.10 | $11.00
R10 | 43.2k | ~ | Resistor_SMD:R_0603_1608Metric | 1 |  | $0.10 | $0.10 | $1.00
R11 | 29.4k | ~ | Resistor_SMD:R_0603_1608Metric | 1 |  | $0.10 | $0.10 | $1.00
R12,R14 | 160k | ~ | Resistor_SMD:R_0603_1608Metric | 2 |  | $0.10 | $0.20 | $2.00
R13 | 30.1k | ~ | Resistor_SMD:R_0603_1608Metric | 1 |  | $0.10 | $0.10 | $1.00
R15,R16,R17,R18,R19,R20,R30,R31,R32,R33,R34,R35,R46,R47,R48,R49,R50,R51,R58,R59,R60,R61,R62,R63,R70,R71,R72,R73,R74,R75 | 62 | ~ | Resistor_SMD:R_0603_1608Metric | 30 |  | $0.10 | $3.00 | $30.00
R21,R26,R27,R36,R90 | 10m | ~ | Resistor_SMD:R_0603_1608Metric | 5 |  | $0.10 | $0.50 | $5.00
R25 | 51k | ~ | Resistor_SMD:R_0603_1608Metric | 1 |  | $0.10 | $0.10 | $1.00
R37,R38,R52,R53,R54,R64,R65,R66,R91,R92 | 1.6k | ~ | Resistor_SMD:R_0603_1608Metric | 10 |  | $0.10 | $1.00 | $10.00
SW1 | TL1105VF100Q | TL1105VF100Q | RoboJackets-Switches:SW_TL1105VF100Q_EWI | 1 |  | $0.40 | $0.40 | $4.00
SW2,SW3,SW4,SW5,SW6 | SW_SPDT | ~ | lib:Slide_Switch_SPDT | 5 |  | $0.40 | $2.00 | $20.00
U1,U12 | MC3486DR | https://www.ti.com/general/docs/suppproductinfo.tsp?distId=10 | lib:SOIC127P600X175-16N | 2 |  | $0.50 | $1.00 | $10.00
U2 | TPS1HTC30AQPWPRQ1 | https://www.ti.com/lit/gpn/tps1htc30-q1 | HTSSOP14_PWP_TEX | 1 |  | $5.00 | $5.00 | $50.00
U3 | LTC2955-1 | https://www.analog.com/media/en/technical-documentation/data-sheets/2955fa.pdf |  | 1 |  | $4.00 | $4.00 | $40.00
U4,U5 | MPM3620GQV-P | https://www.digikey.com/en/htmldatasheets/production/1785101/0/0/1/mpm3620-datasheet | QFN3p0x5p0x1p6_MPM3620_MNP | 2 |  | $2.00 | $4.00 | $40.00
U6,U9,U13,U16,U23 | STSPIN32F0A | https://www.st.com/resource/en/datasheet/stspin32f0.pdf | RoboJackets-IC:IC_STSPIN32F0A | 5 |  | $2.50 | $12.50 | $125.00
U7,U8,U10,U11,U14,U15,U17,U18,U25 | SN74LVC3G17DCTR | https://www.ti.com/lit/ds/symlink/sn74lvc3g17.pdf?ts=1726403224895 | DCT8 | 9 |  | $0.30 | $2.70 | $27.00
U19,U20,U21,U22 | 5102160-1 | https://www.te.com/commerce/DocumentDelivery/DDEController?Action=srchrtrv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 | RoboJackets-Connectors:TYCO_5102160-1 | 4 |  | $4.00 | $16.00 | $160.00
 |  |  |  |  |  |  |  | $2,008.00

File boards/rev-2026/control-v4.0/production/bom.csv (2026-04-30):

Designator | Footprint | Quantity | Value | LCSC Part #
BRD1 | Adafruit_SSD1306_No_Mounting_Holes | 1 | SSD1306
C1 | 0603 | 1 | 10uF
D1, D2 | 0603 | 2 | LED
J1, J2, J3, J4 | 536250274 | 4 | 53625-0274
R1, R2 | 0603 | 2 | 4.7K
R3, R4 | 0603 | 2 | 1K
S1 | HEX | 1 | 94HCB16T
U1 | nRF24L01_Breakout | 1 | NRF24L01_Breakout
U2 | HeaderIMUFooter | 1 | IMU Header
U3 | Teensy41 | 1 | Teensy4.1

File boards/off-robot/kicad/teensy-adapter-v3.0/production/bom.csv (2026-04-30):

Designator | Footprint | Quantity | Value | LCSC Part #
J101 | PinHeader_2x04_P2.54mm_Vertical | 1 | Conn_02x04_Odd_Even
J102 | PinSocket_1x04_P2.54mm_Vertical | 1 | IMU_Left
J103 | PinSocket_1x04_P2.54mm_Vertical | 1 | IMU_Right
R101, R102, R103 | 0603 | 3 | 0
U101 | Teensy41 | 1 | Teensy4.1
U102 | mTrain | 1 | mTrain

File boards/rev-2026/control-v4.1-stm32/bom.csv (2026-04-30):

RefDes | Package | Quantity | Id | LCSC | Digikey | Notes
SW_DIP_SPSTx04_Slide_9.78x12.34mm_W7.62mm_P2.54mm | ~ | 1 | SW3 | https://www.lcsc.com/product-detail/C5299516.html
R_0603_1608Metric | 1k | 6 | R26,R21,R20,R19,R22,R27 | https://www.lcsc.com/product-detail/C22548.html
D_0603_1608Metric | LED (red) | 3 | D12,D13,D14 | https://www.lcsc.com/product-detail/C965799.html
D_0603_1608Metric | LED (green) | 3 | D16,D15,D11 | https://www.lcsc.com/product-detail/C965804.html
SW_PUSH_6mm | SW_Push | 3 | SW1,SW4,SW2 | https://www.lcsc.com/product-detail/C52750873.html
C_0603_1608Metric | 100nF | 8 | C7,C3,C6,C19,C13,C4,C5,C8 | https://www.lcsc.com/product-detail/C14663.html
L_0603_1608Metric | 2.2uH | 1 | L1 | https://www.lcsc.com/product-detail/C394950.html
R_0603_1608Metric | 10k | 5 | R5,R4,R11,R6,R3 | https://www.lcsc.com/product-detail/C98220.html
XTAL_ABM8-25.000MHz-10-B1U-T | 25 MHz 10 pF | 1 | Y1 |  | https://www.digikey.com/en/products/detail/abracon-llc/ABM8-25-000MHZ-10-B1U-T/9997884
R_0603_1608Metric | 5.1k | 2 | R1,R2 | https://www.lcsc.com/product-detail/C105580.html
WE-VE_FEMTOF_0402 | 8231706A | 2 | D6,D7 |  | https://www.digikey.com/en/products/detail/w%C3%BCrth-elektronik/8231706A/11562613
R_0603_1608Metric | 100k | 4 | R25,R24,R15,R18 | https://www.lcsc.com/product-detail/C14675.html
SOD-523_0P9X1P3_ONS | ESD5Z5.0T1G | 7 | D3,D2,D5,D9,D10,D4,D8 | https://www.lcsc.com/product-detail/C82044.html
C_0603_1608Metric | 10pF | 2 | C15,C16 | https://www.lcsc.com/product-detail/C91367.html
R_0603_1608Metric | 330 | 4 | R9,R7,R8,R10 | https://www.lcsc.com/product-detail/C105881.html
536250274 | 53625-0274 | 4 | J1,J4,J3,J5 | https://www.lcsc.com/product-detail/C3640552.html
R_0603_1608Metric | 680k | 1 | R12 | https://www.lcsc.com/product-detail/C98220.html
SOTFL50P160X60-8N | TPS2117DRLR | 2 | U2,U6 | https://www.lcsc.com/product-detail/C22399676.html
R_0603_1608Metric | 210k | 2 | R23,R14 | https://www.lcsc.com/product-detail/C22952.html
C_0603_1608Metric | 2.2uF | 2 | C2,C1 | https://www.lcsc.com/product-detail/C1651.html
C_0603_1608Metric | 4.2uF | 1 | C9 | https://www.lcsc.com/product-detail/C109456.html
SOD2512X115N | B5819WS-TP | 1 | D1 | https://www.lcsc.com/product-detail/C78734.html
USB_C_Receptacle_GCT_USB4110 | USB_C_Receptacle_USB2.0_16P | 1 | J6 | https://www.lcsc.com/product-detail/C5143397.html
LQFP-100_14x14mm_P0.5mm | STM32H723VGTx | 1 | U3 | https://www.lcsc.com/product-detail/C730142.html
SOT-23-5 | TLV62569DBV | 1 | U1 | https://www.lcsc.com/product-detail/C141836.html
R_0603_1608Metric | 150k | 1 | R13 | https://www.lcsc.com/product-detail/C114660.html
C_0603_1608Metric | 1uF | 2 | C12,C14 | https://www.lcsc.com/product-detail/C445753.html
XTAL_ABS07-32.768KHZ-T | 32.768K 7pF | 1 | Y2 |  |  | Not Required Yet
BEADC1608X95N | 1K, 100Mhz | 1 | FB1 | https://www.lcsc.com/product-detail/C50069.html |  | Not Required Yet
C_0603_1608Metric | 10uF | 2 | C21,C22 | https://www.lcsc.com/product-detail/C380314.html
C_0603_1608Metric | 4.7uF | 1 | C10 | https://www.lcsc.com/product-detail/C109456.html
C_0603_1608Metric | 22pF | 1 | C20 | https://www.lcsc.com/product-detail/C105620.html
C_0603_1608Metric | 12pF | 2 | C18,C17 | https://www.lcsc.com/product-detail/C1642.html

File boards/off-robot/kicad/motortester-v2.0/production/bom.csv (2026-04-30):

Designator | Footprint | Quantity | Value | LCSC Part #
C101, C102, C103, C112, C115, C201, C202 | 603 | 7 | 100nF
C104, C105, C106, C107, C108, C116, C117, C118, C119, C120, C121 | 1206 | 11 | 10uF
C109 | 1206 | 1 | 22uF
C110 | 603 | 1 | 1uF
C111 | 2220 | 1 | 47uF
C203, C204 | 603 | 2 | 0.1nF
D101, D102, D103, D104, D105, D106 | 603 | 6 | GREEN
R101, R102, R103, R104, R105, R106, R201, R202 | 603 | 8 | 62
R107, R109, R110, R117, R119 | 603 | 5 | 1k
R108 | 603 | 1 | 4.7k
R111 | 1206 | 1 | 2m
R112 | 603 | 1 | 270k
R113, R120, R121 | 603 | 3 | 100k
R114 | 603 | 1 | 63.4k
R115 | 603 | 1 | 160k
R116 | 603 | 1 | 30.1k
R118 | 603 | 1 | 10k
U101 | IC_STSPIN32F0A | 1 | STSPIN32F0A
U105 | SOT-23-5 | 1 | INA180A3
U201, U202 | SOP65P400X130-8N | 2 | SN74LVC3G17DCTR
U203 | SOIC127P600X175-16N | 1 | MC3486DR

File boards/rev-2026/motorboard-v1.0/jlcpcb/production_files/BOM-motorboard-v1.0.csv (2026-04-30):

Comment | Designator | Footprint | LCSC | Quantity
01530007Z | X1 | FUSE_01530007Z | C206906 | 1
100 pF | C10,C30,C31,C51,C52,C72,C73,C9 | C_0603_1608Metric | C14858 | 8
100k | R21 | R_0603_1608Metric | C25803 | 1
100nF | C1,C11,C13,C14,C15,C17,C19,C32,C34,C35,C36,C38,C40,C53,C55,C56,C57,C59,C61,C74,C76,C77,C78,C80,C82,C93,C95,C96,C97,C98 | C_0603_1608Metric | C14663 | 30
10k | R11,R14,R22,R37,R5,R52,R67,R8,R82 | R_0603_1608Metric | C25804 | 9
10m | R31,R46,R61,R76,R89 | R_1206_3216Metric | C20803 | 5
10nF | C16,C37,C58,C79 | C_1206_3216Metric | C1846 | 4
10nF | C6 | C_0603_1608Metric | C57112 | 1
10uF | C100,C101,C102,C104,C105,C106,C107,C108,C109,C18,C2,C20,C21,C22,C24,C25,C26,C27,C28,C29,C39,C41,C42,C43,C45,C46,C47,C48,C49,C5,C50,C60,C62,C63,C64,C66,C67,C68,C69,C70,C71,C81,C83,C84,C85,C87,C88,C89,C90,C91,C92,C99 | C_1206_3216Metric | C13585 | 52
120 | R23,R24,R38,R39,R53,R54,R68,R69 | R_0603_1608Metric | C22787 | 8
160k | R12,R17,R6 | R_0603_1608Metric | C22813 | 3
1k | R10,R16,R19,R2,R3,R32,R33,R34,R47,R48,R49,R62,R63,R64,R77,R78,R79,R90,R91,R92 | R_0603_1608Metric | C21190 | 20
1uF | C12,C33,C54,C75,C94 | C_0603_1608Metric | C15849 | 5
220uF | C103,C23,C44,C65,C86 | CP_Elec_6.3x7.7 | C2836441 | 5
22uF | C3,C4,C8 | C_1206_3216Metric | C12891 | 3
29.4k | R15 | R_0603_1608Metric | C22974 | 1
30.1k | R13 | R_0603_1608Metric | C2960871 | 1
3k | R9 | R_0603_1608Metric | C4211 | 1
43.2k | R7 | R_0603_1608Metric | C23053 | 1
470nF | C7 | C_0603_1608Metric | C1623 | 1
5.6k | R1,R35,R36,R50,R51,R65,R66,R80,R81 | R_0603_1608Metric | C23189 | 9
51k | R18 | R_0603_1608Metric | C23196 | 1
52901-0274 | J4,J5,J8,J9 | 529010274 | C564018 | 4
590k | R20 | R_0603_1608Metric | C185318 | 1
62 | R25,R26,R27,R28,R29,R30,R40,R41,R42,R43,R44,R45,R55,R56,R57,R58,R59,R60,R70,R71,R72,R73,R74,R75,R83,R84,R85,R86,R87,R88 | R_0603_1608Metric | C23222 | 30
68k | R4 | R_0603_1608Metric | C23231 | 1
7.5k | R93,R94 | R_0603_1608Metric | C23234 | 2
B3J-1100 | SW1 | B3J-1000 | C2733628 | 1
BSS123 | Q14,Q21,Q28,Q35,Q7 | SOT-23 | C79015 | 5
D2510-6002-AR | J17,J20,J23,J26 | CONN_6002RB_3MM | C17659136 | 4
FSV10100V | U2 | DIO_10100V_ONS | C7422633 | 1
GREEN | D1,D2,D3,D4,D5,D6,D7,D8 | D_0603_1608Metric | C12624 | 8
HFW8R-1STE1H1LF | J14 | AMPHENOL_HFW8R-1STE1H1LF | C3169775 | 1
LTC2955-1 | U5 | SOT65P280X100-8N | C580659 | 1
MPM3620GQV-P | U1,U4 | MPM3620GQVP | C6675393 | 2
R | R95,R96,R97 | R_0603_1608Metric | C23212 | 3
S8B-PH-SM4-TB | J28 | CONN_S8B-PH-SM4-TB_JST | C265121 | 1
SN74LVC3G17DCUR | U12,U13,U16,U17,U20,U21,U23,U8,U9 | SOP50P310X90-8N | C18213 | 9
SN75157DR | U11,U15,U19,U7 | SOIC127P599X175-8N | C2861519 | 4
STD140N6F7 | Q1,Q10,Q11,Q12,Q13,Q15,Q16,Q17,Q18,Q19,Q2,Q20,Q22,Q23,Q24,Q25,Q26,Q27,Q29,Q3,Q30,Q31,Q32,Q33,Q34,Q4,Q5,Q6,Q8,Q9 | DPAKTO-252_A2_STM | C513091 | 30
STSPIN32F0A | U10,U14,U18,U22,U6 | IC_STSPIN32F0A | C1520987 | 5
VN5E006ASPTR-E | U3 | SO_E006ASP-E_STM | C2150096 | 1
XT30PW-M | J12 | XT30PWM | C431092 | 1
XT60PW-M | J15 | XT60PWM | C98732 | 1

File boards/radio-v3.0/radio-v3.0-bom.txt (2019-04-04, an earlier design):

Partlist exported from /home/robojackets/robocup-pcb/boards/radio-v3.0/radio-v3.0.sch at 3/22/19 1:34 PM

Qty Value              Device             Package              Parts                                       Description                DIGIKEY       MPN                  SPICEPREFIX VALUE 
2                      PINHD-1X3          1X03                 JP1, JP2                                    PIN HEADER                                                                      
5   0.1uF              C-USC0603          C0603                C5, C6, C13, C14, C15                       CAPACITOR, American symbol                                    C                 
1   100k               R-US_R0603         R0603                R2                                          RESISTOR, American symbol                                                       
4   10uF               C-USC1210          C1210                C2, C3, C9, C10                             CAPACITOR, American symbol                                    C                 
1   10uF 16V           C-USC1210          C1210                C7                                          CAPACITOR, American symbol                                    C                 
1   143.0k 1%          R-US_R0603         R0603                R3                                          RESISTOR, American symbol                                     R                 
10  1k                 R-US_R0603         R0603                R5, R6, R7, R8, R9, R10, R11, R12, R13, R14 RESISTOR, American symbol                                                       
2   1uF                C-USC0603          C0603                C4, C12                                     CAPACITOR, American symbol                                    C                 
2   220uF              ECA-0JM221         ECA-0JM221-HGT_HORIZ C1, C8                                                                                                                      
1   22uF               C-USC1210          C1210                C11                                         CAPACITOR, American symbol                                    C                 
1   45.3k 1%           R-US_R0603         R0603                R4                                          RESISTOR, American symbol                                     R                 
1   88.7k 1%           R-US_R0603         R0603                R1                                          RESISTOR, American symbol                                                       
6   GREEN              LED-SMD-GREEN      CHIP-LED0603         D1, D2, D3, D5, D7, D9                                                 160-1446-1-ND LTST-C191KGKT                    GREEN 
2   ISM43340           ISM43340           ISM43340             U1, U3                                                                                                                      
1   MPM3620GQV-P       MPM3620GQV-P       MPM3620GQV-P         U2                                                                                                                          
2   RED                LED-SMD-RED        CHIP-LED0603         D4, D8                                                                 160-1447-1-ND LTST-C191KRKT                    RED   
1   SBH11-PBPC-D05-ST  SBH11-PBPC-D05-ST  SFH11-*-D05-ST       J1                                                                     S9194-ND      SFH11-PBPC-D05-ST-BK                   
4   SOLDERBRIDGESB0603 SOLDERBRIDGESB0603 SB0603               SB1, SB2, SB3, SB4                                                                                                          
2   TC2050-IDC-NL      TC2050-IDC-NL      TC2050-IDC-NL        J2, J3                                                                                                                      
2   YELLOW             LED-SMD-YELLOW     CHIP-LED0603         D6, D10                                                                160-1448-1-ND LTST-C191KSKT                    YELLOW

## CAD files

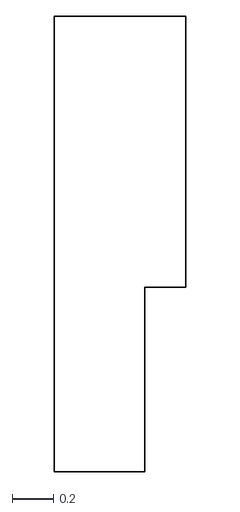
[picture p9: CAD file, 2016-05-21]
boards/capacitor-board-2015-c/capacitor-board.dxf
0.64 x 2.22

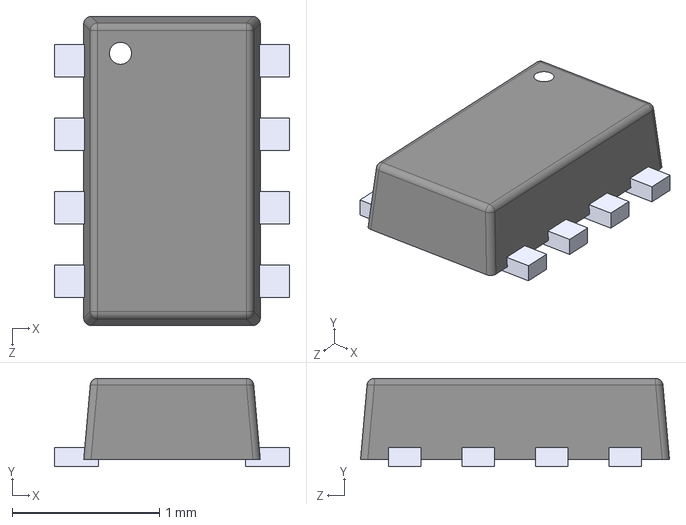
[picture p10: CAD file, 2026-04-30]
boards/rev-2026/control-v4.1-stm32/footprints/TPS2117DRLR.step
1.60 x 0.6 x 2.10 mm

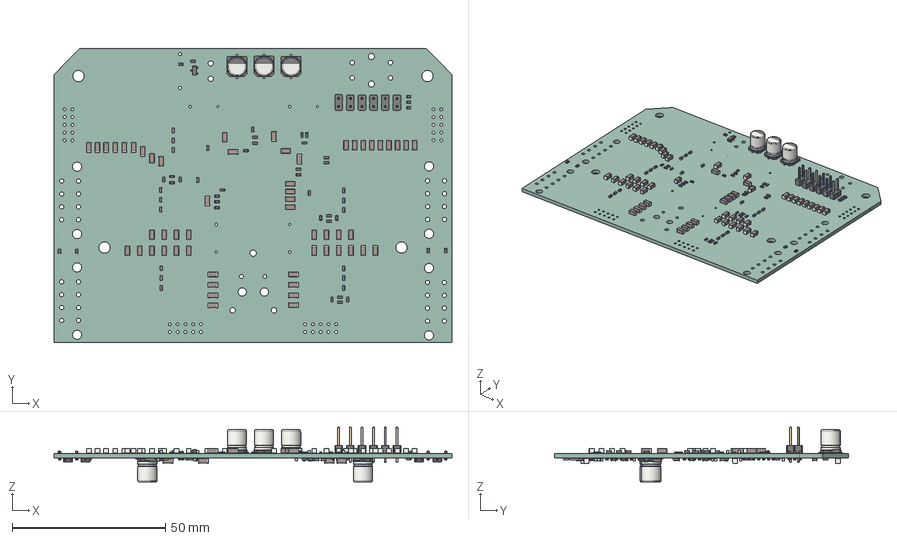
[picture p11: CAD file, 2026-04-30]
boards/rev-2026/motorboard-v1.0/motorboard-v1.0.step
130.0 x 96.0 x 17.9 mm
C_1206_3216Metric x 60
R_0603_1608Metric x 79
C_0603_1608Metric x 43
D_0603 x 8
CP_Elec_63x77 x 5
PinHeader_1x02_P254mm_Vertical x 6
SOT_23 x 5
R_1206_3216Metric x 5
motorboard-v1.0_PCB

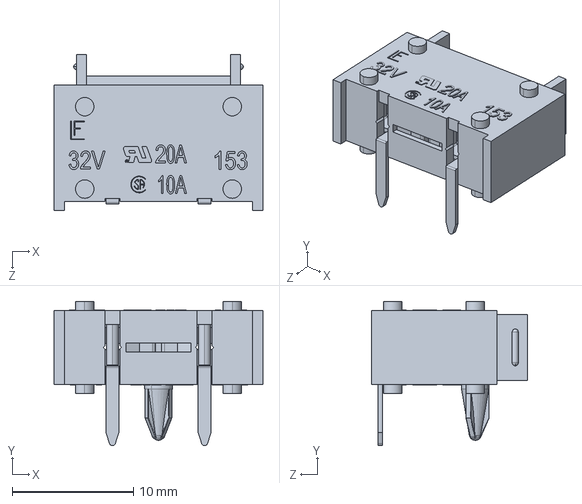
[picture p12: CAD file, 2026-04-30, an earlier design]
boards/rev-2026/kicker-v3.4/piman-lib/3D/OL-01530007Z.step
17.3 x 11.9 x 12.9 mm

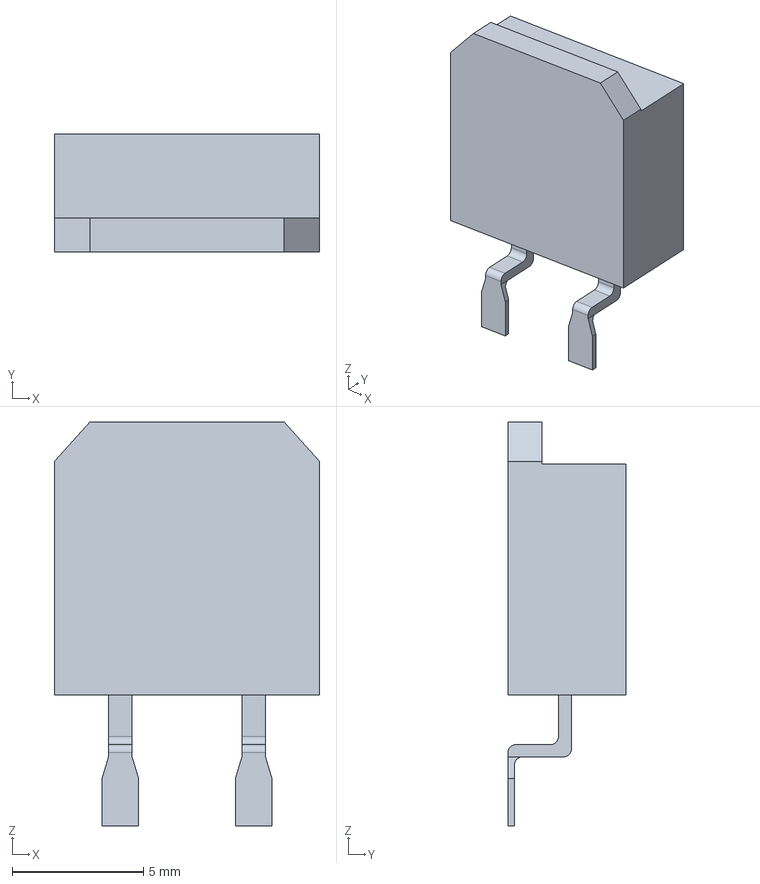
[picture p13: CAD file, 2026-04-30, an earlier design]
boards/rev-2026/kicker-v3.4/piman-lib/3D/pwr263s-35.stp
10.1 x 4.50 x 15.4 mm

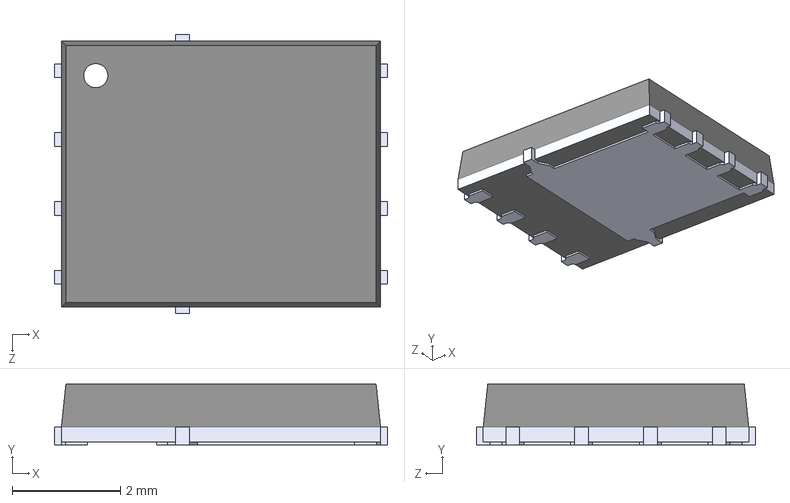
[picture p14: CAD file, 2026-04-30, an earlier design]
boards/rev-2026/kicker-v3.4/piman-lib/3D/SI7149ADP-T1-GE3.STEP
6.15 x 1.12 x 5.16 mm

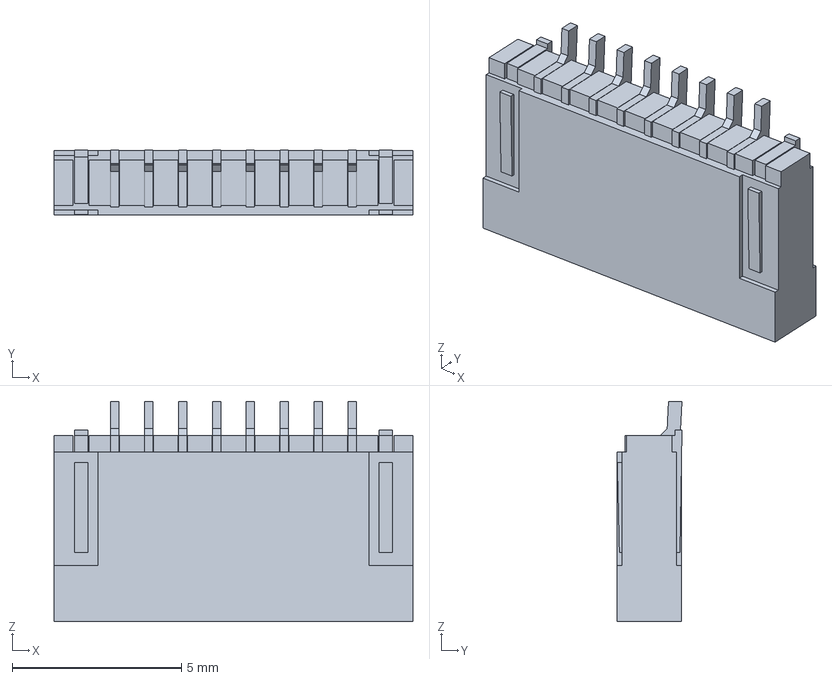
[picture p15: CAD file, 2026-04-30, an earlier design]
boards/rev-2026/kicker-v3.4/piman-lib/3D/HFW8R-1STE1H1LF--3DModel-STEP-533217.STEP
10.6 x 1.92 x 6.50 mm

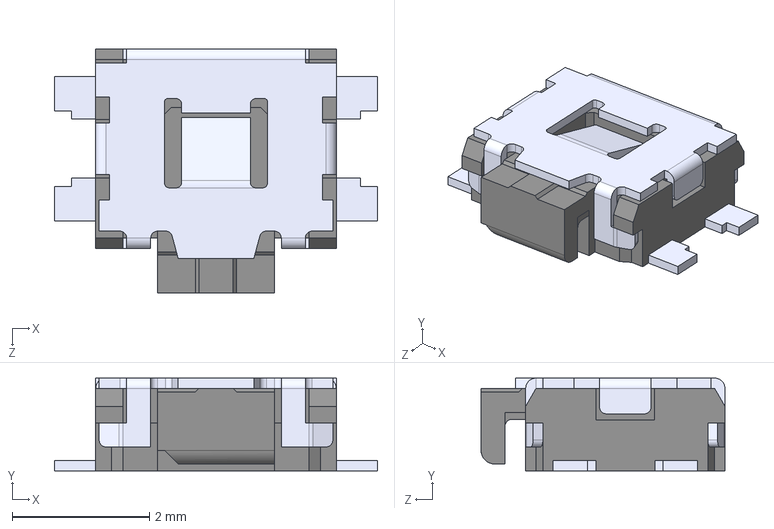
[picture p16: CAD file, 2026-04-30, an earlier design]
boards/rev-2026/kicker-v3.4/piman-lib/3D/EVQ-P7A01P.step
4.70 x 1.35 x 3.55 mm

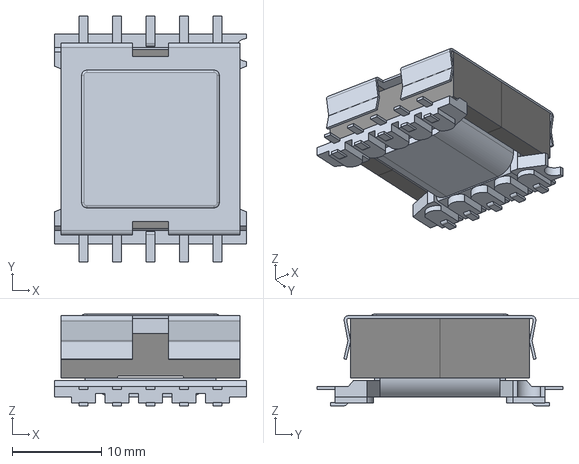
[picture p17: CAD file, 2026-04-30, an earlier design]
boards/rev-2026/kicker-v3.4/piman-lib/3D/WE-FB_3751_EFD20_1.stp
21.5 x 27.5 x 10.2 mm

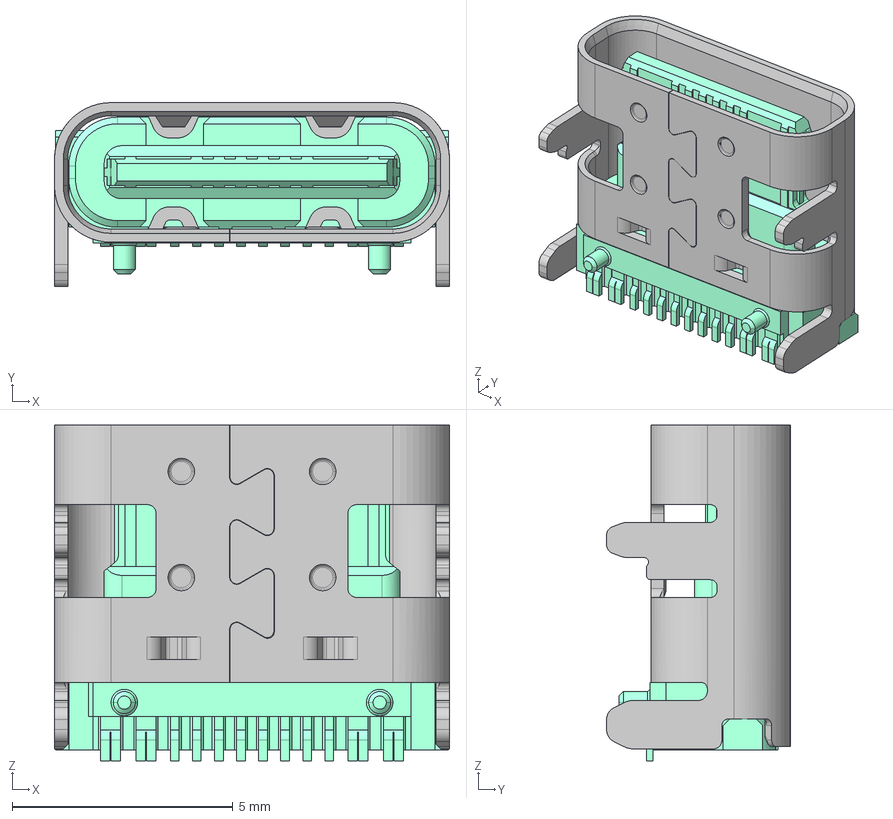
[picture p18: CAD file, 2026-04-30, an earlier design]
boards/rev-2026/kicker-v3.4/piman-lib/3D/12402012E212A.step
8.94 x 4.16 x 7.60 mm

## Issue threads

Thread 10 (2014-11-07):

Create circuit capable of auto discharging kicker capacitors

jjones646, 2014-11-07:

jjones646, 2015-03-08:
moving issue tracking off github

Closed 2015-03-08.

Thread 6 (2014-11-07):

Create and route board for FPGA signals between mbed and motor controller circuit

jjones646, 2014-11-07:
max dimensions: 2: x 3.5"

jjones646, 2015-03-08:
moving issue tracking off github

Closed 2015-03-08.

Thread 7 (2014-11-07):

Create Kicker Board 2015 schematic

jjones646, 2014-11-07:

jjones646, 2015-03-08:
moving issue tracking off github

Closed 2015-03-08.

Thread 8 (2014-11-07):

Add on board kicker tests buttons to control board schematic

jjones646, 2014-11-07:

jjones646, 2015-03-08:
moving issue tracking off github

Closed 2015-03-08.

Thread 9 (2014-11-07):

Add interface for operating motors through just control board into the schematic

jjones646, 2014-11-07:

jjones646, 2015-03-08:
moving issue tracking off github

Closed 2015-03-08.

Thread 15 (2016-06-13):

Create pcb for 2015 base station

justbuchanan, 2016-06-13:
This won't be anything fancy, just something simple so we don't have to use in place of a breadboard.

cc @jjones646

jjones646, 2016-06-13:
probably will want to support 2 radios on separate spi busses.

justbuchanan, 2016-06-13:
Good call.  We talked about doing that before, but I had completely forgotten about it.

justbuchanan, 2016-06-14:
@jjones646 any idea where I can find an eagle library for this part?

http://www.digikey.com/product-search/en/connectors-interconnects/rectangular-board-to-board-connectors-headers-male-pins/1442672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

justbuchanan, 2016-06-14:
Also, what's the best way to show connections to the mbed in the schematic?  The board will have the female headers for the mbed to plug into, but it would be nice in the schematic to show the pinout of the mbed.  I guess I could just add the headers to the schematic and label the relevant pins, but I'm not sure if there's a better way to use the mbed.

jjones646, 2016-06-14:
make it :smile:. It's a super easy part, just make the pads shorter than what the datasheet recommends...

There should be an mbed library part in the repo somehwere

justbuchanan, 2016-06-15:
Sounds good, I should be able to handle that.

Yeah I see the mbed library in this repo.  My question was more of should I put the headers in the schematic or the mbed itself?  Or both?  The pcb will just have two rows of headers mounted on it.

jjones646, 2016-06-16:
Just the mbed in the schematic should work out fine.

Closed 2016-07-10.

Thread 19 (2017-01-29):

FPGA pins flipped during configuration

petersonev, 2017-01-29:
Warning in firmware ` #warning FPGA configuration pins currently flipped due to PCB design errors, the final revision requires firmware updates.`

petersonev, 2017-03-29:
Issue should be fixed on new control board with 4bb605c357fa999e92b364981c592ced56307e44. Not closing issue until confirmed through testing

petersonev, 2017-04-24:
Tested and configuration pins fixed, software SPI no longer needed in firmware

Closed 2017-04-24.

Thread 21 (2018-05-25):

Update Control Board to Spartan 7

guyfleeman, 2018-05-25:
We should work toward a control board that supports the Spartan 7 for a few reasons.

1. ISE is approaching EoL/EoS
2. The newest version of Verilog supported is 2001 (17 years ago)
3. No SV Support
4. Outdated Xilinx IP

This is needed to address [this firmware issue](https://github.com/RoboJackets/robocup-firmware/issues/54).

The candidate replacement chip seems to be the Spartan 7 [XC7S25](https://www.digikey.com/product-detail/en/xilinx-inc/XC7S25-1FTGB196C/122-2122-ND/8040787) which is several times more powerful than the current [Spartan 3E - XC3S250E](https://www.xilinx.com/publications/prod_mktg/spartan-3-product-table.pdf) that we use.

Desired Added Feature List
- [ ] Spartan 7
- [ ] Current Sensing on Motor Phase Lines

guyfleeman, 2018-05-25:
So the Spartan 7 is 196-LFBGA. What would be a cost estimate per board if we did this at M-Train quality?

petersonev, 2018-05-25:
Looks like the pitch is 1mm instead of 0.8 so we might be able to get away with a cheaper classification. I'll check eurocircuits to find the exact cost. But upgrading the classification on eurocircuits is actually not that much, especially with large quantities.

guyfleeman, 2018-05-25:
I'm comfortable trying to port the current control scheme to the 7 but probably not adding the current sense.

guyfleeman, 2018-05-25:
@petersonev what are you interested in working on? Or are you sticking with M-Chair software rn?

petersonev, 2018-05-25:
I'll keep working on the new MCU board stuff but I'll at least make a PCB with the spartan 7 so that can get ordered first thing in the year. I'll definitely try to help on verilog stuff too (as much as I can) because I want to get better at that

guyfleeman, 2018-05-25:
So what do you want me to work on first/rn? SV sim or Spartan 7 port?

petersonev, 2018-05-25:
SV sim is probably better to get started on first, especially because you have a lot more experience with system verilog

guyfleeman, 2018-05-25:
Okay. I almost want to try routing that board tho when the schematic is done. Defs keep me in the loop

petersonev, 2018-05-25:
On eurocircuits we should actually be able to still use class 6 and just upgrade the drill size to 0.15mm so that's only like $10 extra total which is basically nothing. I may still upgrade to class 7 so the routing can be nicer because that's only like $30 extra total. I'll have exact prices later but the change in PCB cost should be negligible

guyfleeman, 2018-05-25:
Good

Closed 2022-05-14.

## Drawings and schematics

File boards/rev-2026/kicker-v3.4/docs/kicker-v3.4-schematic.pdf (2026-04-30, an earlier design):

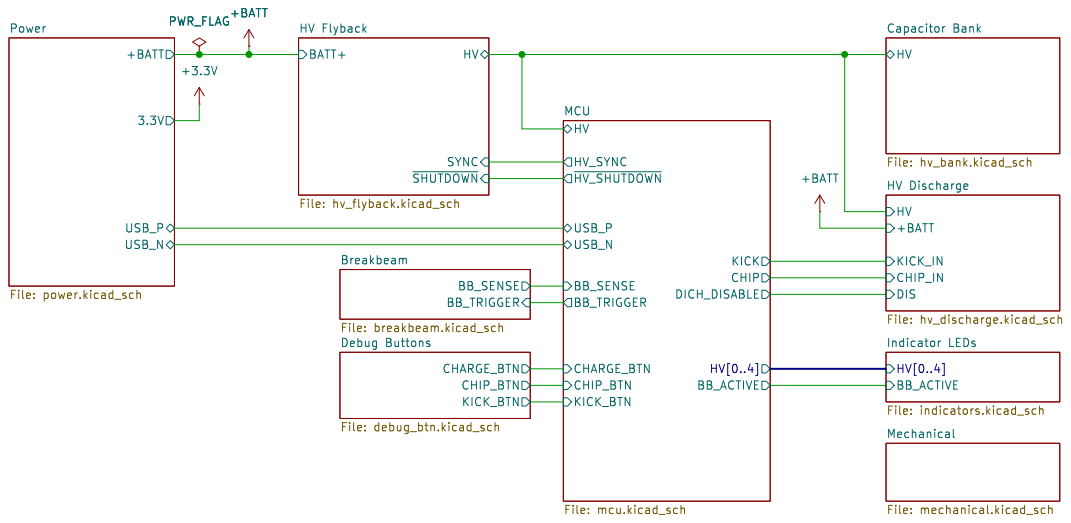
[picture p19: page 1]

~{SHUTDOWN} HV Flyback File: hv_flyback.kicad_sch +BATT

Id: 1/10 Title: Kicker Board

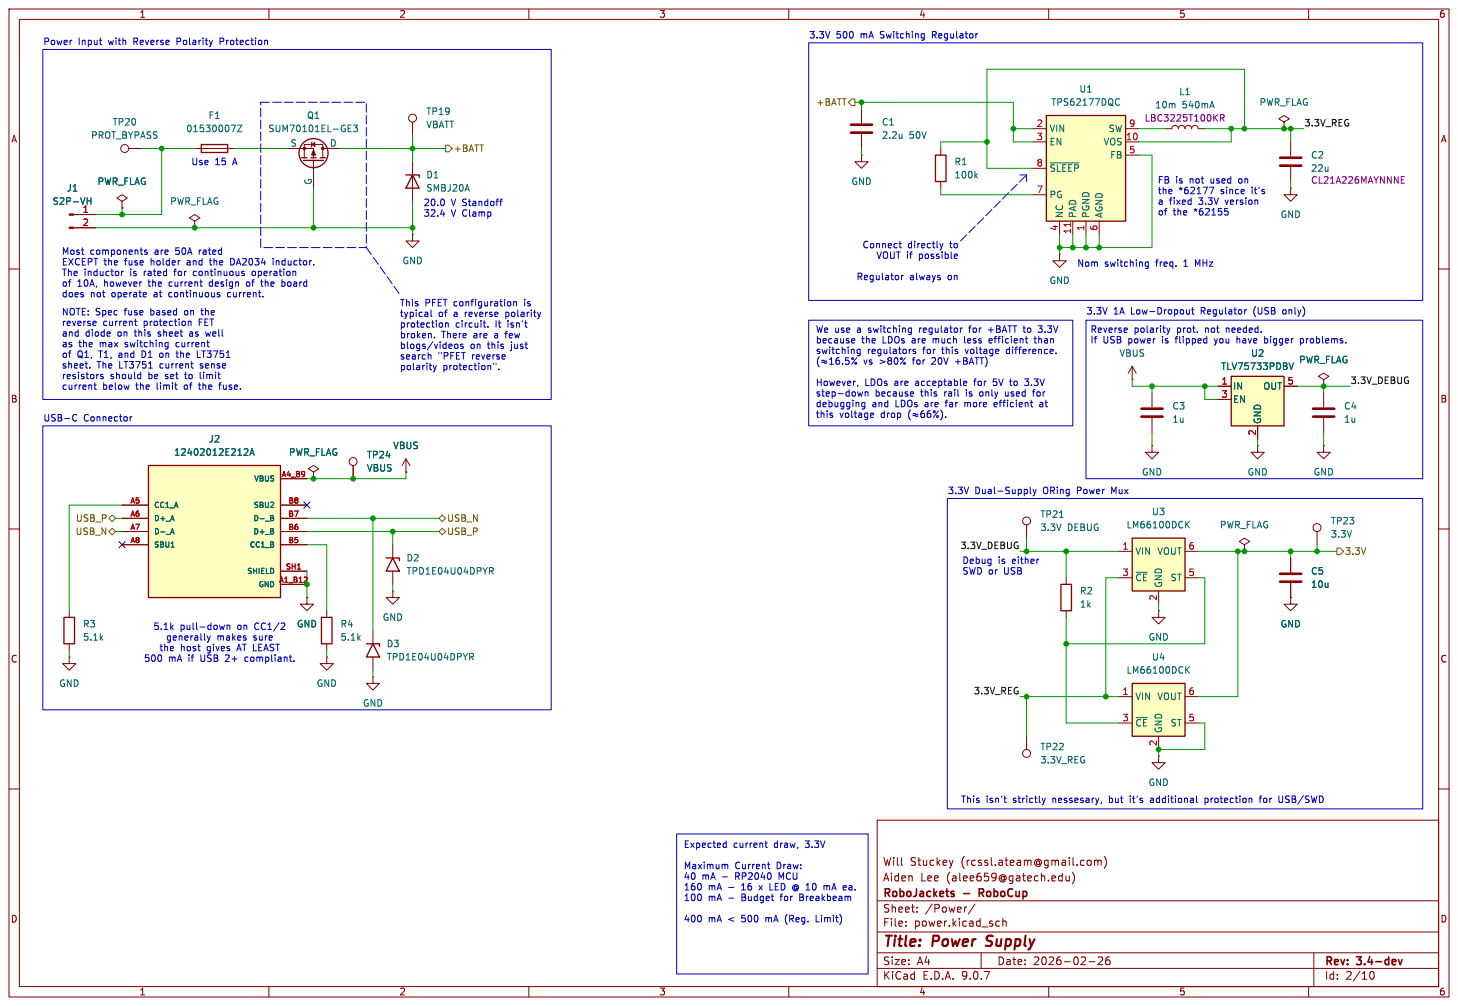
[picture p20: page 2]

of 10A, however the current design of the board

USB-C Connector NOTE: Spec fuse based on the

sheet. The LT3751 current sense

3.3V_DEBUG
Debug is either SWD or USB

the host gives AT LEAST

160 mA - 16 x LED @ 10 mA ea. 100 mA - Budget for Breakbeam

400 mA < 500 mA (Reg. Limit)

Id: 2/10 Title: Power Supply

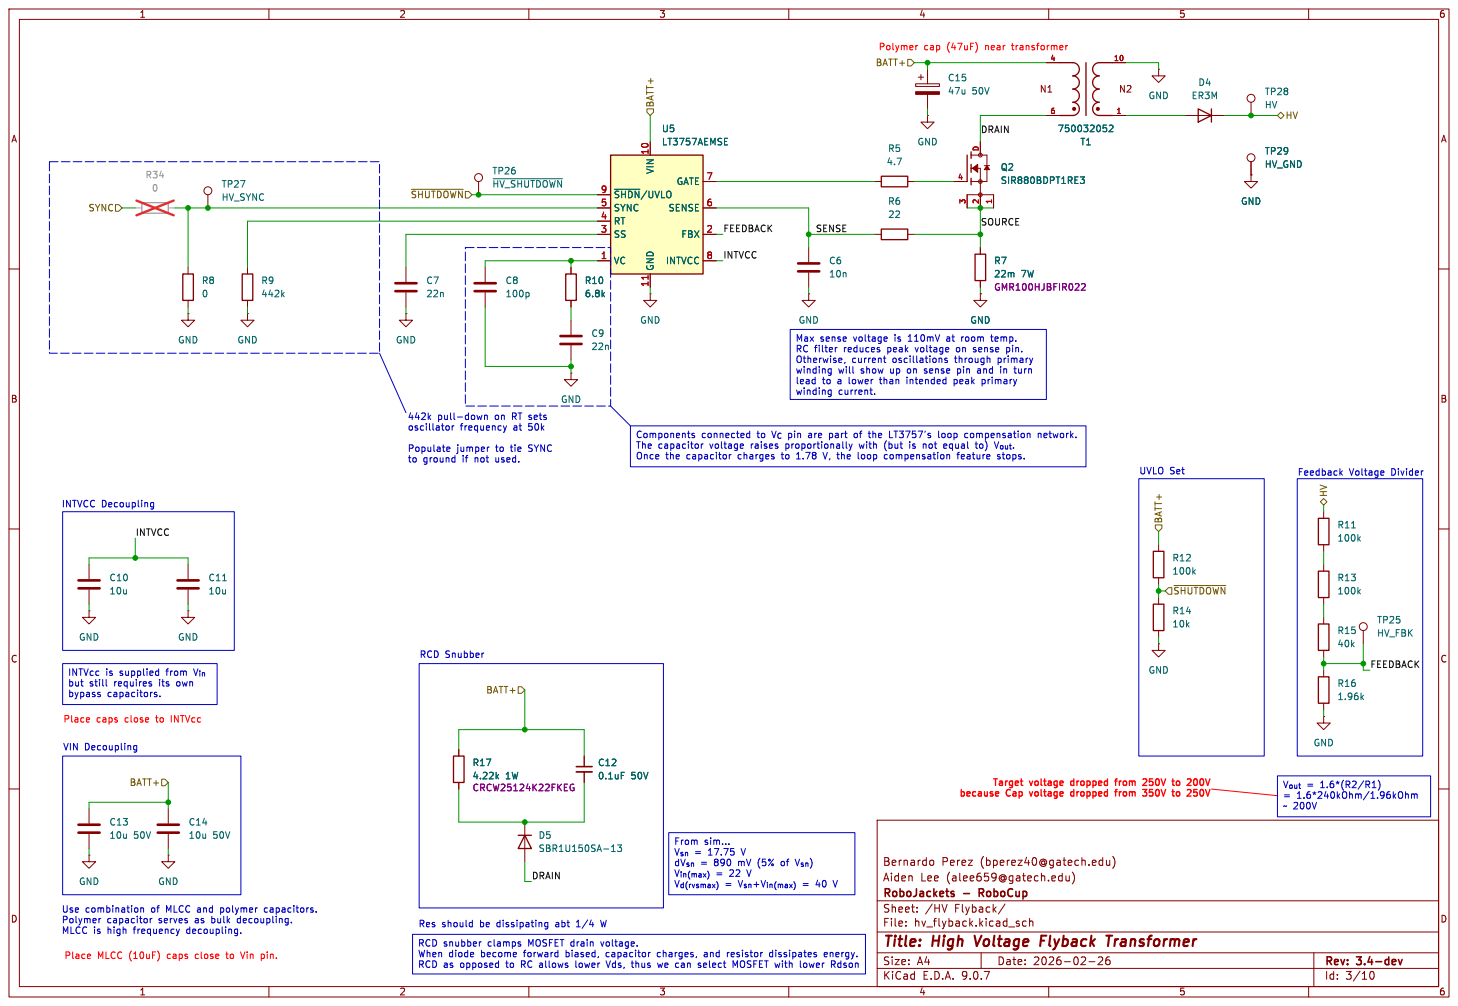
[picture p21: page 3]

winding will show up on sense pin and in turn

Target voltage dropped from 250V to 200V

because Cap voltage dropped from 350V to 250V

V_{in(max)}= 22 V
V_{d(rvsmax)}= V_{sn}+V_{in(max)} = 40 V

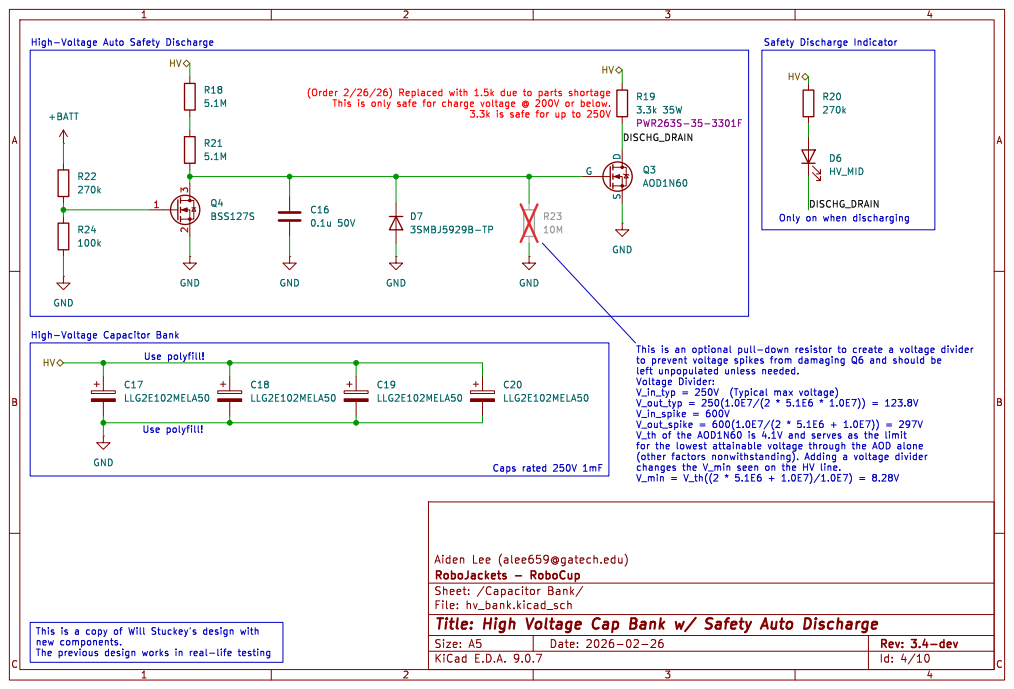
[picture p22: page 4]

This is only safe for charge voltage @ 200V or below.

3.3k is safe for up to 250V

DISCHG_DRAIN
Only on when discharging

Voltage Divider:
V_in_spike = 600V
V_th of the AOD1N60 is 4.1V and serves as the limit
changes the V_min seen on the HV line.

Title: High Voltage Cap Bank w/ Safety Auto Discharge

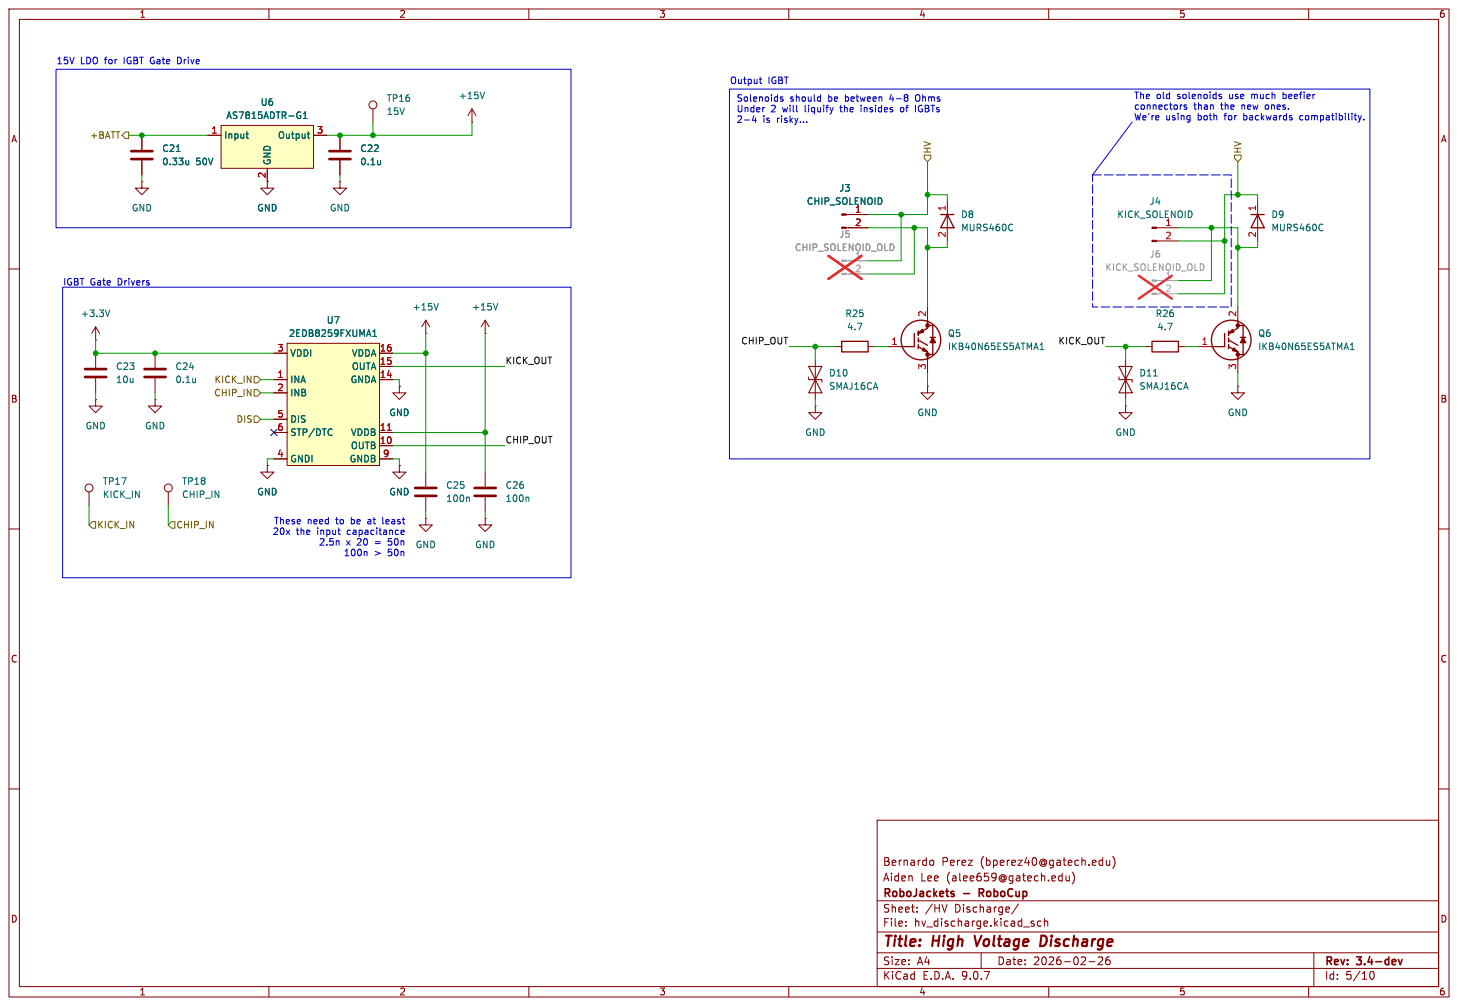
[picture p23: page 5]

15V LDO for IGBT Gate Drive
+BATT KICK_IN

2 Output 3 U6 AS7815ADTR-G1 GND GND GND GND

Id: 5/10 Title: High Voltage Discharge

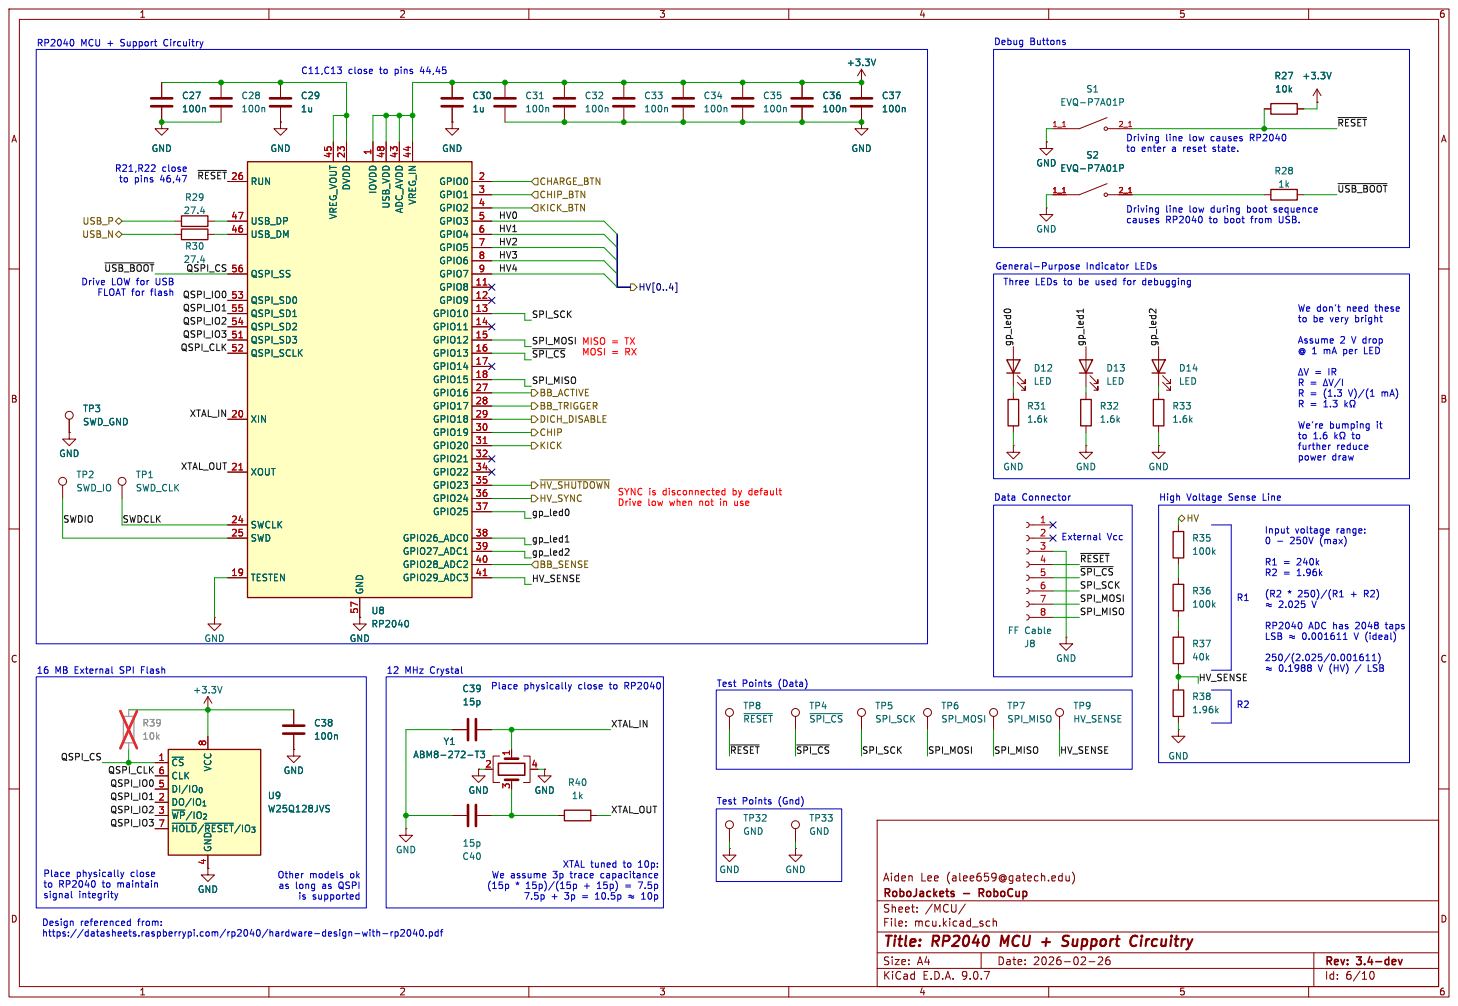
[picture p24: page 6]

Debug Buttons MISO = TX MOSI = RX

to enter a reset state. R21,R22 close

Driving line low during boot sequence
causes RP2040 to boot from USB.

to be very bright Assume 2 V drop @ 1 mA per LED

þÿ"H0.1988 V (HV) / LSB Other models ok as long as QSPI

XTAL tuned to 10p: We assume 3p trace capacitance

Id: 6/10 Title: RP2040 MCU + Support Circuitry

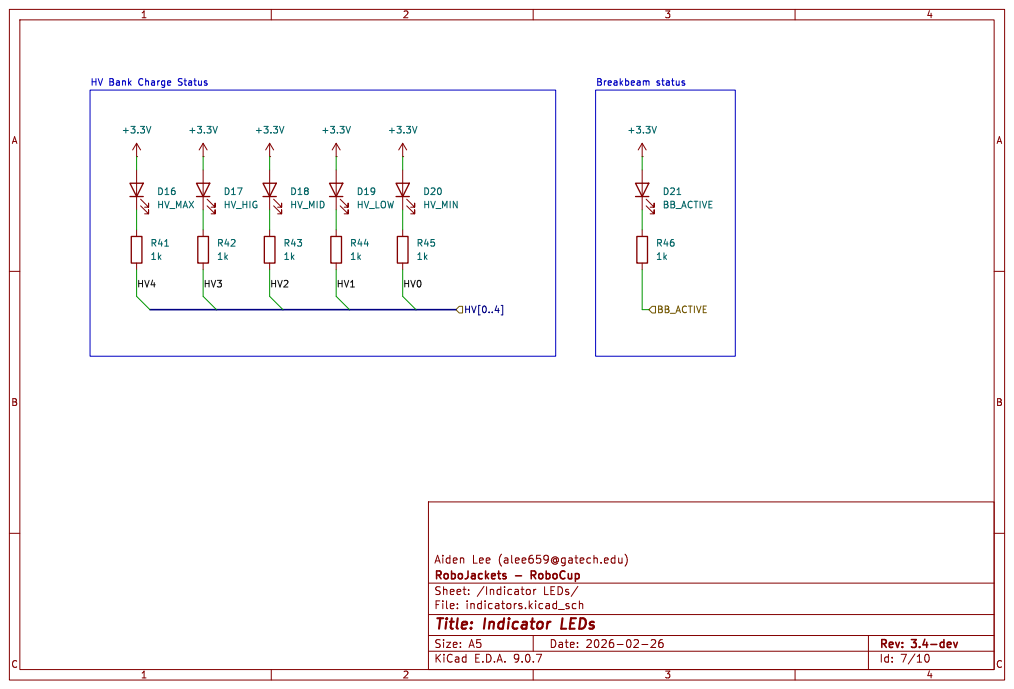
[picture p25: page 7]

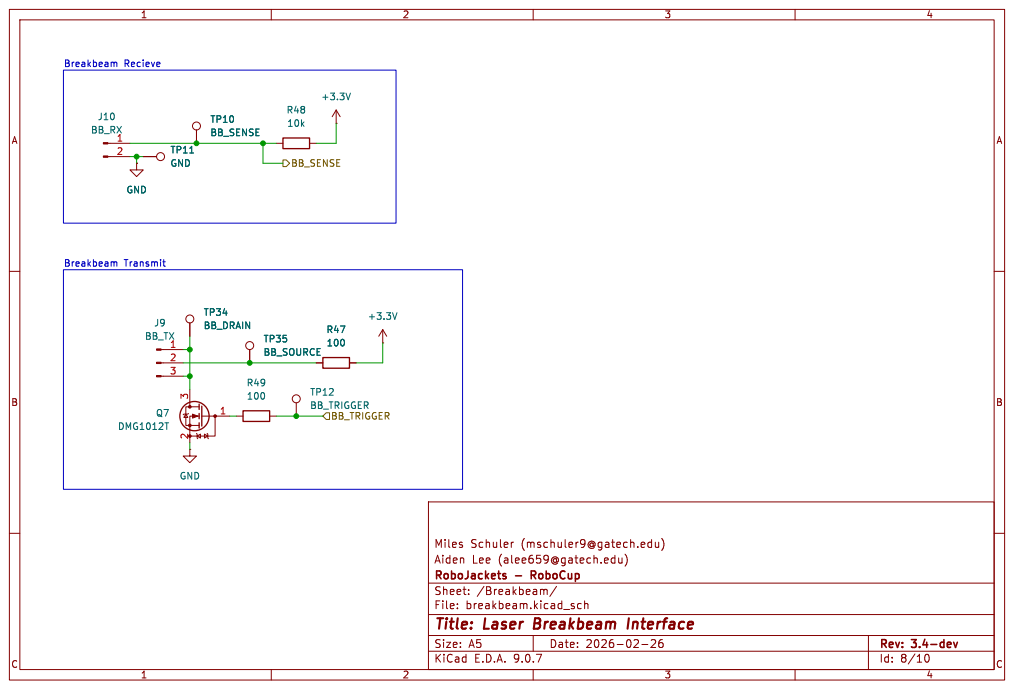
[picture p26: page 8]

Sheet: /Breakbeam/
Title: Laser Breakbeam Interface

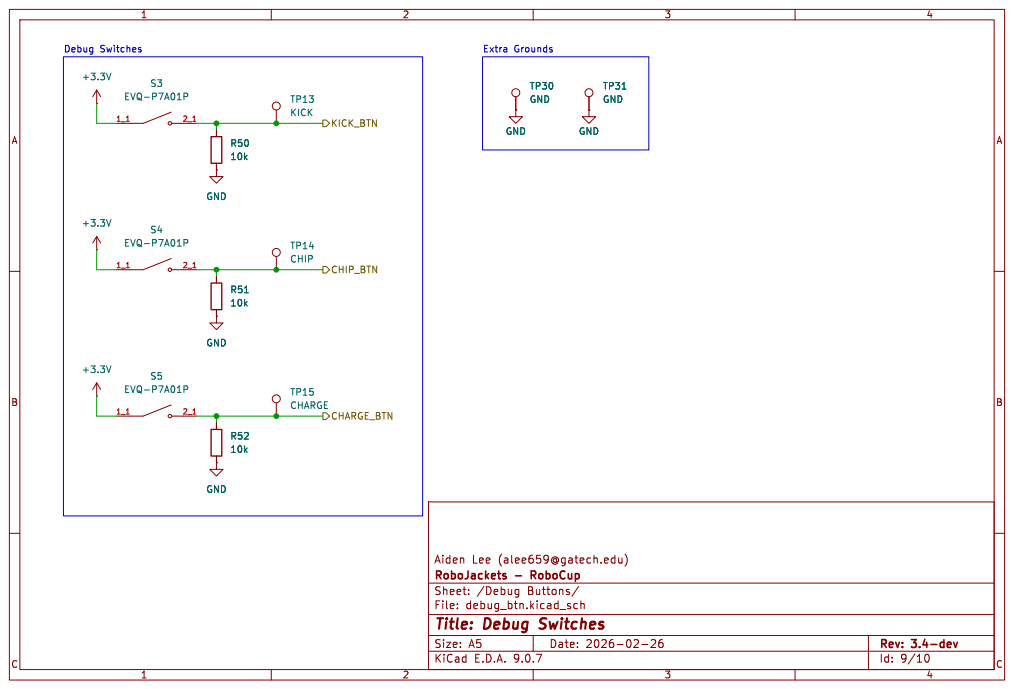
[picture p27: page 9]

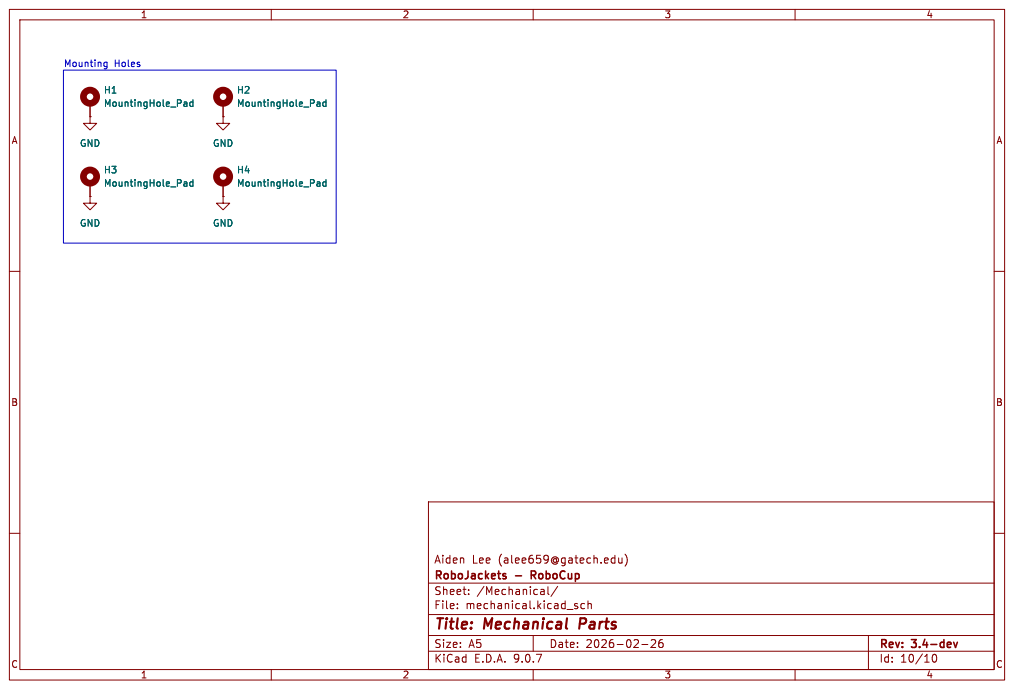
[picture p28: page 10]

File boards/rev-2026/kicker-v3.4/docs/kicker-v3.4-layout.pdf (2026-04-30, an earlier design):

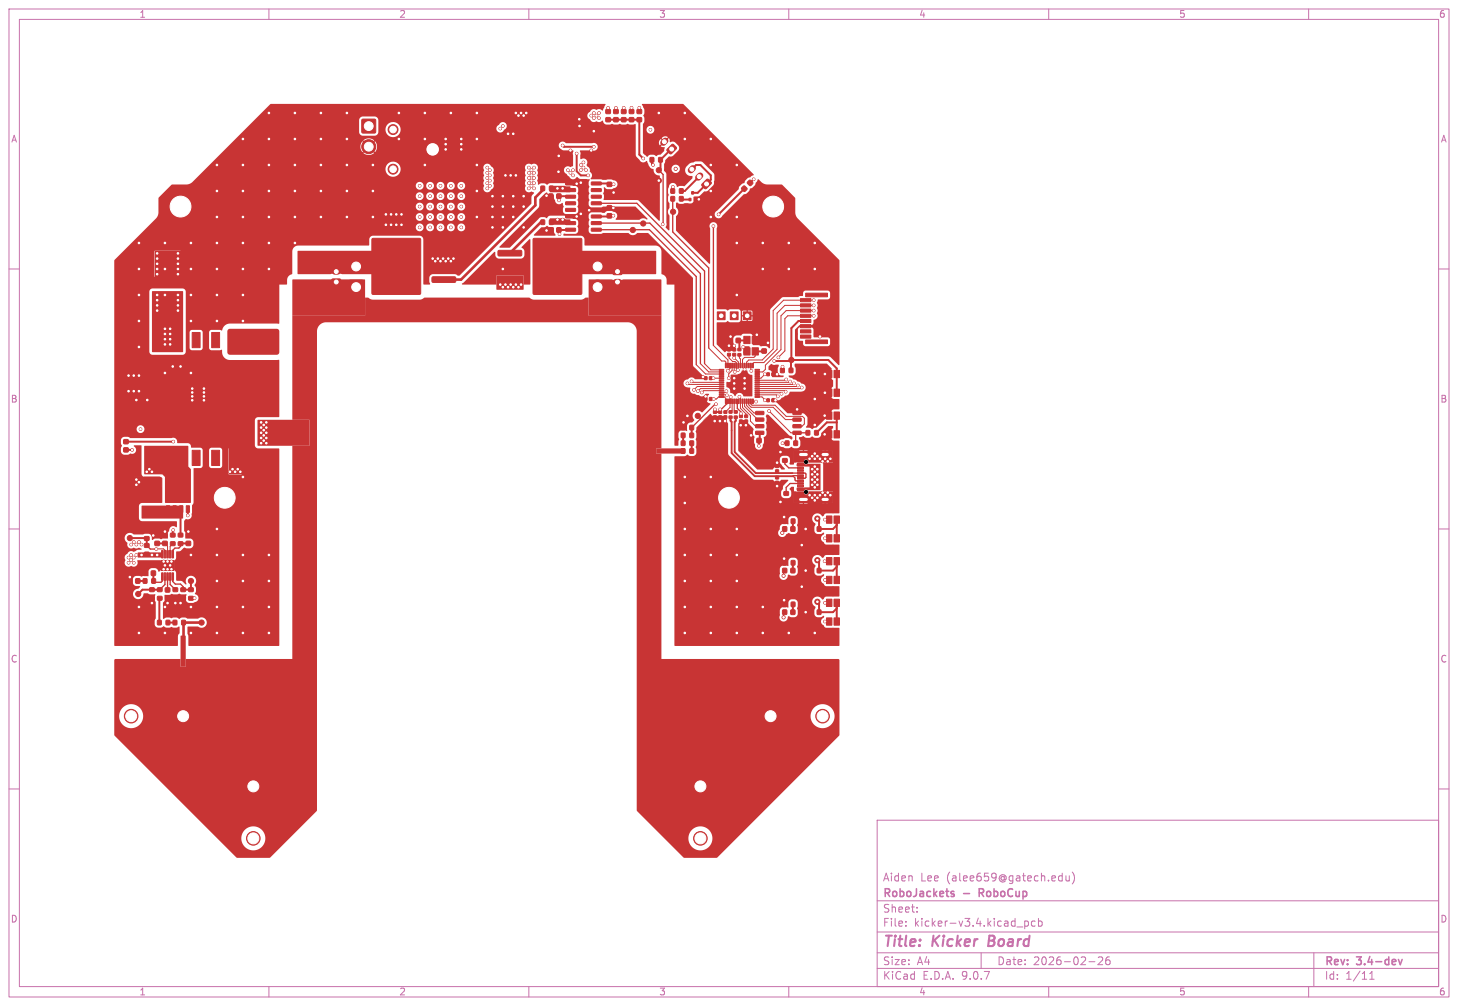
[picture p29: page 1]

Id: 1/11 Title: Kicker Board

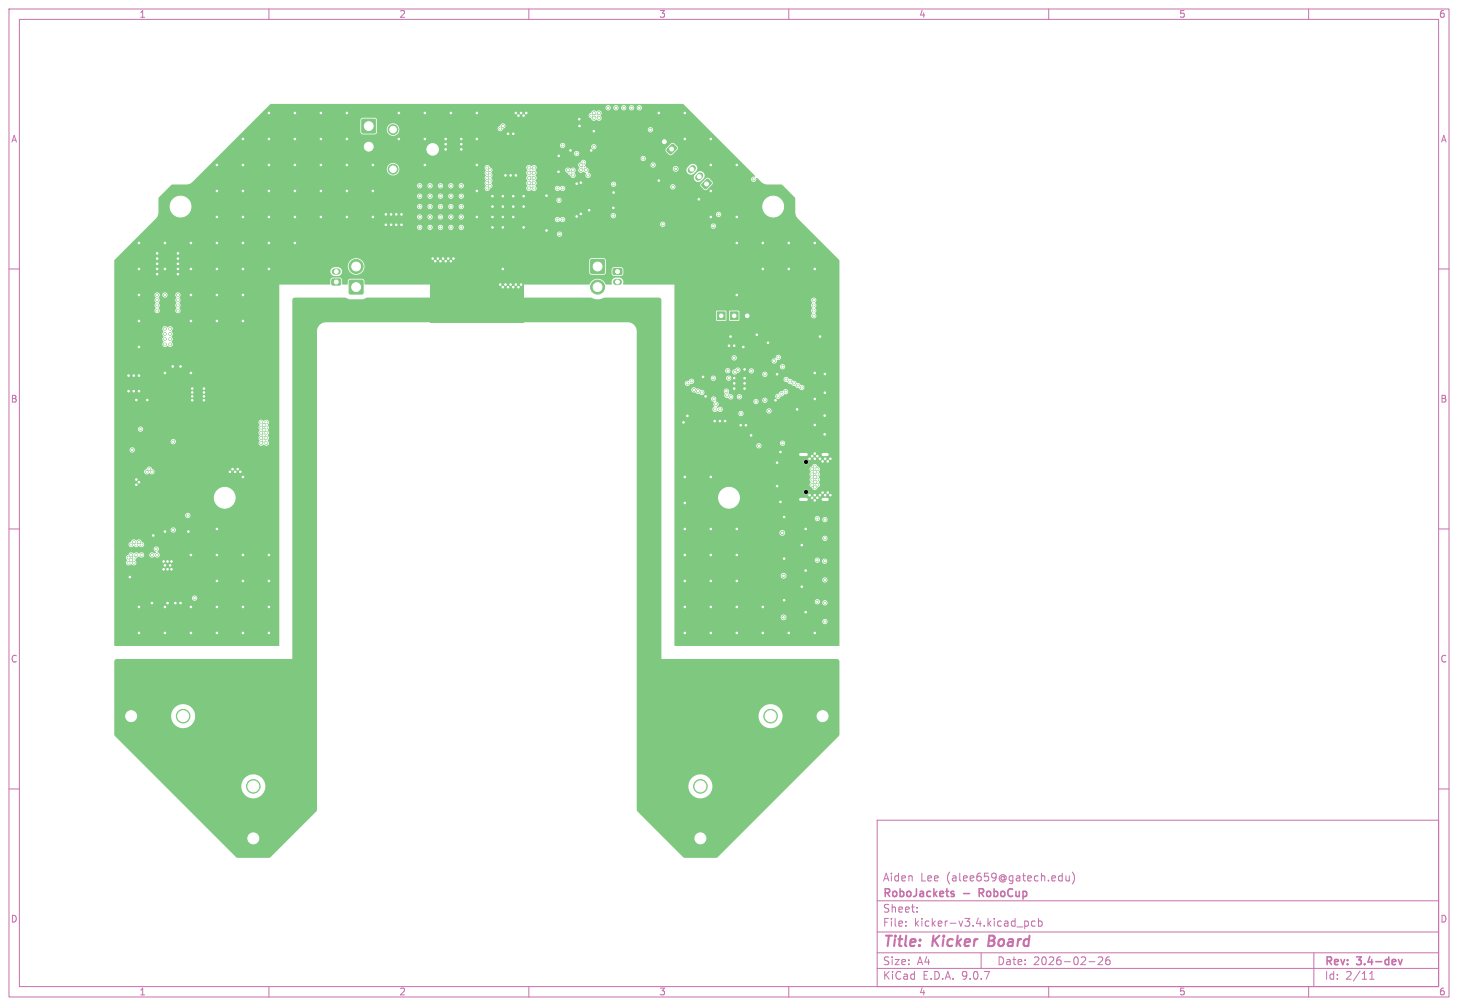
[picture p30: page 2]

Id: 2/11 Title: Kicker Board


Id: 3/11 Title: Kicker Board


Id: 4/11 Title: Kicker Board


Id: 5/11 Title: Kicker Board


Id: 6/11 Title: Kicker Board


Id: 7/11 Title: Kicker Board


Id: 8/11 Title: Kicker Board


Id: 9/11 Title: Kicker Board


Id: 10/11 Title: Kicker Board


Id: 11/11 Title: Kicker Board

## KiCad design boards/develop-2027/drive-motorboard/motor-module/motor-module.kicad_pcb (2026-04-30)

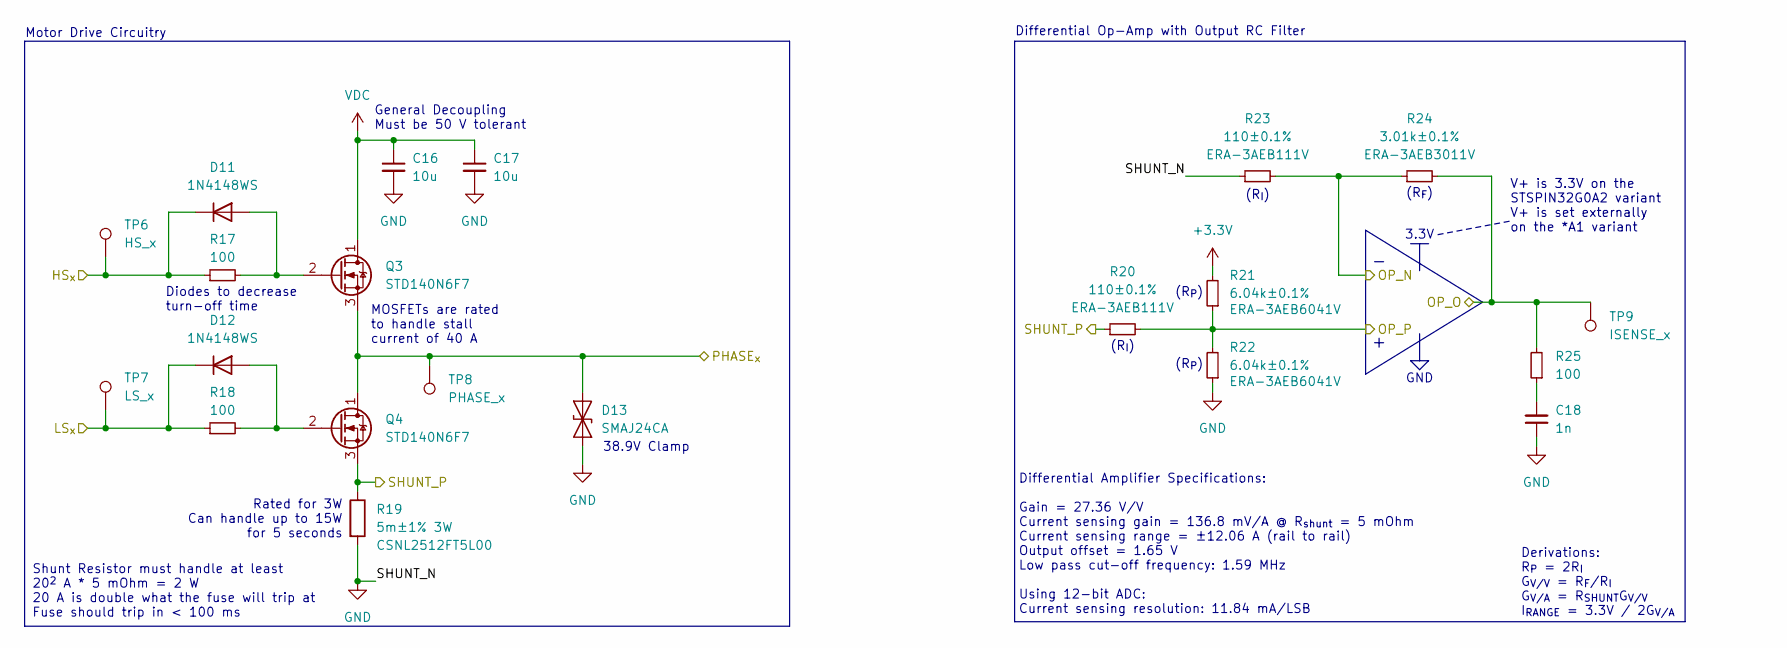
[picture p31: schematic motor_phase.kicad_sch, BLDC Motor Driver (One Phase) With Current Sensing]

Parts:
C16, C17: 10u; C_1206_3216Metric
C18: 1n; C_0603_1608Metric
D11, D12: 1N4148WS; D_SOD-323; Manufacturer P/N 1N4148WS
D13: SMAJ24CA; D_SMA; Manufacturer P/N SMAJ24CA
Q3, Q4: STD140N6F7; TO-252-2; Manufacturer P/N STD140N6F7
R17, R18, R25: 100; R_0603_1608Metric
R19: 5m±1% 3W; R_2512_6332Metric; Manufacturer P/N CSNL2512FT5L00
R20, R23: 110±0.1%; R_0603_1608Metric; Manufacturer P/N ERA-3AEB111V
R21, R22: 6.04k±0.1%; R_0603_1608Metric; Manufacturer P/N ERA-3AEB6041V
R24: 3.01k±0.1%; R_0603_1608Metric; Manufacturer P/N ERA-3AEB3011V
TP6: HS_x; R_1206_3216Metric; Manufacturer P/N RCWCTE
TP7: LS_x; R_1206_3216Metric; Manufacturer P/N RCWCTE
TP8: PHASE_x; R_1206_3216Metric; Manufacturer P/N RCWCTE
TP9: ISENSE_x; R_1206_3216Metric; Manufacturer P/N RCWCTE

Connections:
+3.3V: R21.2; also elsewhere on the board
/Microcontroller/HS_U: D11.1 (K), R17.1, TP6.1; also elsewhere on the board
/Microcontroller/ISENSE_U: R24.2, R25.2, TP9.1; also elsewhere on the board
/Microcontroller/LS_U: D12.1 (K), R18.1, TP7.1; also elsewhere on the board
/Microcontroller/OP_U_N: R23.2, R24.1; also elsewhere on the board
/Microcontroller/OP_U_P: R20.2, R21.1, R22.2; also elsewhere on the board
/PHASE_U: D13.2 (A2), Q3.3, Q4.1, TP8.1; also elsewhere on the board
/SHUNT_U: Q4.3, R19.1, R20.1; also elsewhere on the board
GND: C16.2, C17.2, C18.1, D13.1 (A1), R19.2, R22.1, R23.1; also elsewhere on the board
unnamed: C18.2, R25.1
unnamed: D11.2 (A), Q3.2, R17.2
unnamed: D12.2 (A), Q4.2, R18.2
VDC: C16.1, C17.1, Q3.1; also elsewhere on the board

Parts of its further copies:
C19, C20, C22, C23: 10u; C_1206_3216Metric
C21, C24: 1n; C_0603_1608Metric
D14, D15, D17, D18: 1N4148WS; D_SOD-323; Manufacturer P/N 1N4148WS
D16, D19: SMAJ24CA; D_SMA; Manufacturer P/N SMAJ24CA
Q5, Q6, Q7, Q8: STD140N6F7; TO-252-2; Manufacturer P/N STD140N6F7
R26, R27, R34, R35, R36, R43: 100; R_0603_1608Metric
R28, R37: 5m±1% 3W; R_2512_6332Metric; Manufacturer P/N CSNL2512FT5L00
R29, R32, R38, R41: 110±0.1%; R_0603_1608Metric; Manufacturer P/N ERA-3AEB111V
R30, R31, R39, R40: 6.04k±0.1%; R_0603_1608Metric; Manufacturer P/N ERA-3AEB6041V
R33, R42: 3.01k±0.1%; R_0603_1608Metric; Manufacturer P/N ERA-3AEB3011V
TP10, TP14: HS_x; R_1206_3216Metric; Manufacturer P/N RCWCTE
TP11, TP15: LS_x; R_1206_3216Metric; Manufacturer P/N RCWCTE
TP12, TP16: PHASE_x; R_1206_3216Metric; Manufacturer P/N RCWCTE
TP13, TP17: ISENSE_x; R_1206_3216Metric; Manufacturer P/N RCWCTE

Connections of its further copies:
+3.3V: R30.2, R39.2; also elsewhere on the board
/Microcontroller/HS_V: D14.1 (K), R26.1, TP10.1; also elsewhere on the board
/Microcontroller/HS_W: D17.1 (K), R35.1, TP14.1; also elsewhere on the board
/Microcontroller/ISENSE_V: R33.2, R34.2, TP13.1; also elsewhere on the board
/Microcontroller/ISENSE_W: R42.2, R43.2, TP17.1; also elsewhere on the board
/Microcontroller/LS_V: D15.1 (K), R27.1, TP11.1; also elsewhere on the board
/Microcontroller/LS_W: D18.1 (K), R36.1, TP15.1; also elsewhere on the board
/Microcontroller/OP_V_N: R32.2, R33.1; also elsewhere on the board
/Microcontroller/OP_V_P: R29.2, R30.1, R31.2; also elsewhere on the board
/Microcontroller/OP_W_N: R41.2, R42.1; also elsewhere on the board
/Microcontroller/OP_W_P: R38.2, R39.1, R40.2; also elsewhere on the board
/PHASE_V: D16.2 (A2), Q5.3, Q6.1, TP12.1; also elsewhere on the board
/PHASE_W: D19.2 (A2), Q7.3, Q8.1, TP16.1; also elsewhere on the board
/SHUNT_V: Q6.3, R28.1, R29.1; also elsewhere on the board
/SHUNT_W: Q8.3, R37.1, R38.1; also elsewhere on the board
GND: C19.2, C20.2, C21.1, C22.2, C23.2, C24.1, D16.1 (A1), D19.1 (A1), R28.2, R31.1, R32.1, R37.2, R40.1, R41.1; also elsewhere on the board
unnamed: C21.2, R34.1
unnamed: C24.2, R43.1
unnamed: D14.2 (A), Q5.2, R26.2
unnamed: D15.2 (A), Q6.2, R27.2
unnamed: D17.2 (A), Q7.2, R35.2
unnamed: D18.2 (A), Q8.2, R36.2
VDC: C19.1, C20.1, C22.1, C23.1, Q5.1, Q7.1; also elsewhere on the board

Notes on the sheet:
38.9V Clamp
Shunt Resistor must handle at least 20^{2} A * 5 mOhm = 2 W 20 A is double what the fuse will trip at Fuse should trip in < 100 ms
Motor Drive Circuitry
MOSFETs are rated to handle stall current of 40 A
(R_{I})
Differential Op-Amp with Output RC Filter
Diodes to decrease turn-off time
(R_{P})
3.3V
General Decoupling Must be 50 V tolerant
(R_{F})
Differential Amplifier Specifications: Gain = 27.36 V/V Current sensing gain = 136.8 mV/A @ R_{shunt} = 5 mOhm Current sensing range = ±12.06 A (rail to rail) Output offset = 1.65 V Low pass cut-off frequency: 1.59 MHz Using 12-bit ADC: Current sensing resolution: 11.84 mA/LSB
GND
V+ is 3.3V on the STSPIN32G0A2 variant V+ is set externally on the *A1 variant
Rated for 3W Can handle up to 15W for 5 seconds
Derivations: R_{P} = 2R_{I} G_{V/V} = R_{F}/R_{I} G_{V/A} = R_{SHUNT}G_{V/V} I_{RANGE} = 3.3V / 2G_{V/A}

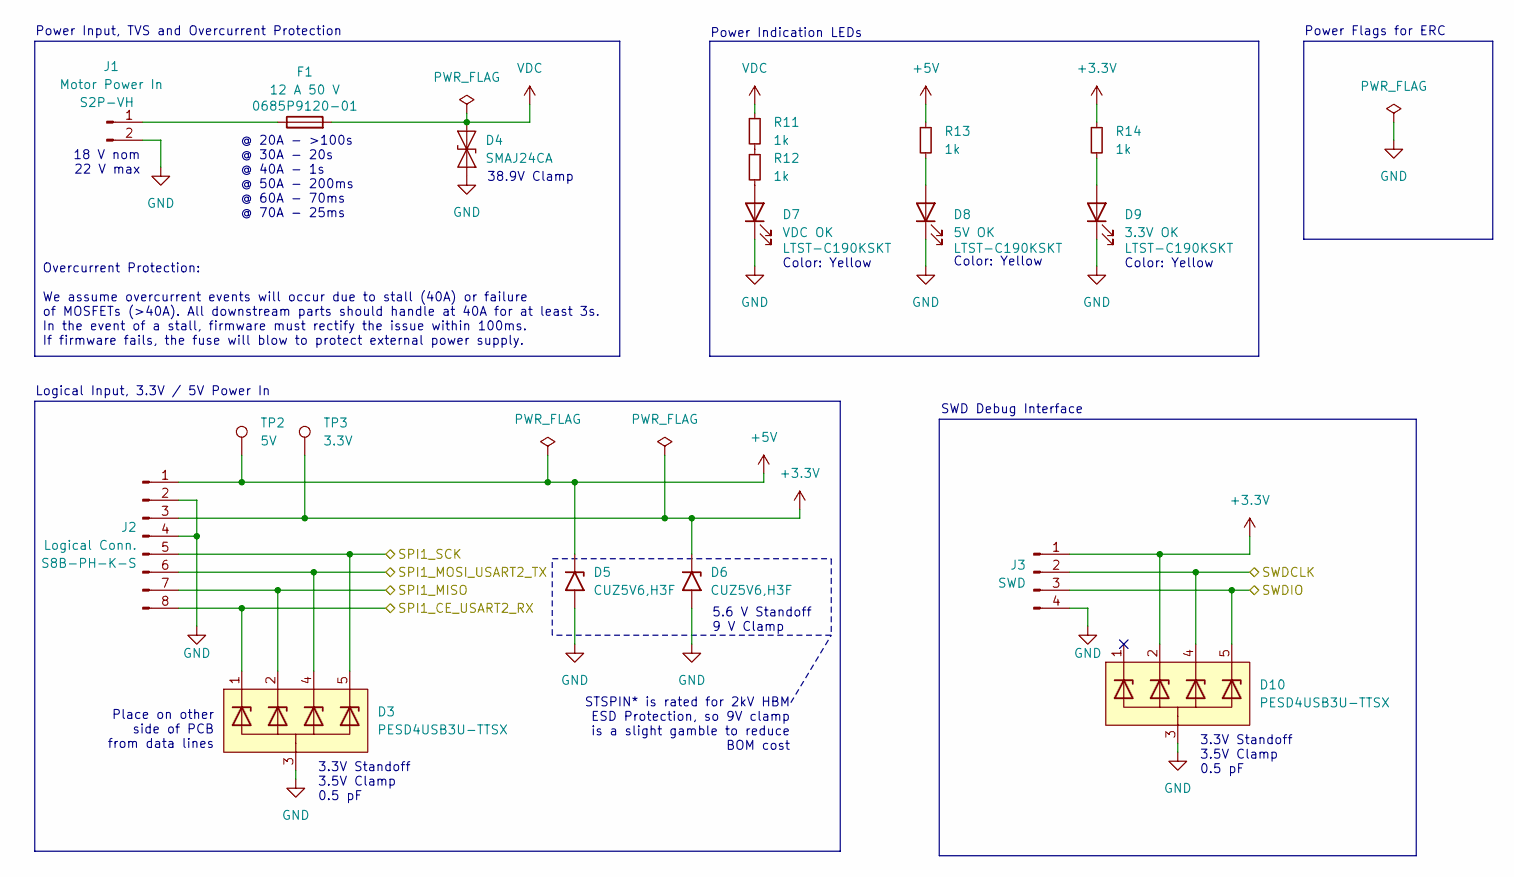
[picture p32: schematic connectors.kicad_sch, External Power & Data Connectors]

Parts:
D3, D10: PESD4USB3U-TTSX; Manufacturer P/N PESD4USB3U-TTSX
D4: SMAJ24CA; D_SMA; Manufacturer P/N SMAJ24CA
D5, D6: CUZ5V6,H3F; D_SOD-323F; Manufacturer P/N CUZ5V6,H3F
D7: VDC OK; LED_0603_1608Metric; Manufacturer P/N LTST-C190KSKT
D8: 5V OK; LED_0603_1608Metric; Manufacturer P/N LTST-C190KSKT
D9: 3.3V OK; LED_0603_1608Metric; Manufacturer P/N LTST-C190KSKT
F1: 12 A 50 V; Fuse_1206_3216Metric; Manufacturer P/N 0685P9120-01
J1: Motor Power In; JST_VH_S2P-VH_1x02_P3.96mm_Horizontal; Manufacturer P/N S2P-VH
J2: Logical Conn.; JST_PH_S8B-PH-K_1x08_P2.00mm_Horizontal; Manufacturer P/N S8B-PH-K-S
J3: SWD
R11, R12, R13, R14: 1k; R_0603_1608Metric
TP2: 5V; R_1206_3216Metric; Manufacturer P/N RCWCTE
TP3: 3.3V; R_1206_3216Metric; Manufacturer P/N RCWCTE

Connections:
+3.3V: D6.1 (A1), D10.2, J2.3, J3.1, R14.1, TP3.1; also elsewhere on the board
+5V: D5.1 (A1), J2.1, R13.1, TP2.1; also elsewhere on the board
/Microcontroller/SPI1_CE_USART2_RX: D3.1, J2.8; also elsewhere on the board
/Microcontroller/SPI1_MISO: D3.2, J2.7; also elsewhere on the board
/Microcontroller/SPI1_MOSI_USART2_TX: D3.4, J2.6; also elsewhere on the board
/Microcontroller/SPI1_SCK: D3.5, J2.5; also elsewhere on the board
GND: D3.3 (A), D3.8, D4.1 (A1), D5.2 (A2), D6.2 (A2), D7.1 (K), D8.1 (K), D9.1 (K), D10.3 (A), D10.8, J1.2, J2.2, J2.4, J3.4; also elsewhere on the board
unnamed: D7.2 (A), R12.2
unnamed: D8.2 (A), R13.2
unnamed: D9.2 (A), R14.2
unnamed: D10.4, J3.2
unnamed: D10.5, J3.3
unnamed: F1.1, J1.1
unnamed: R11.2, R12.1
VDC: D4.2 (A2), F1.2, R11.1; also elsewhere on the board

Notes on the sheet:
Power Input, TVS and Overcurrent Protection
3.3V Standoff 3.5V Clamp 0.5 pF
38.9V Clamp
Power Indication LEDs
Place on other side of PCB from data lines
Logical Input, 3.3V / 5V Power In
Color: Yellow
STSPIN* is rated for 2kV HBM ESD Protection, so 9V clamp is a slight gamble to reduce BOM cost
18 V nom 22 V max
@ 20A - >100s @ 30A - 20s @ 40A - 1s @ 50A - 200ms @ 60A - 70ms @ 70A - 25ms
Overcurrent Protection: We assume overcurrent events will occur due to stall (40A) or failure of MOSFETs (>40A). All downstream parts should handle at 40A for at least 3s. In the event of a stall, firmware must rectify the issue within 100ms. If firmware fails, the fuse will blow to protect externa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
Power Flags for ERC
SWD Debug Interface
5.6 V Standoff 9 V Clamp

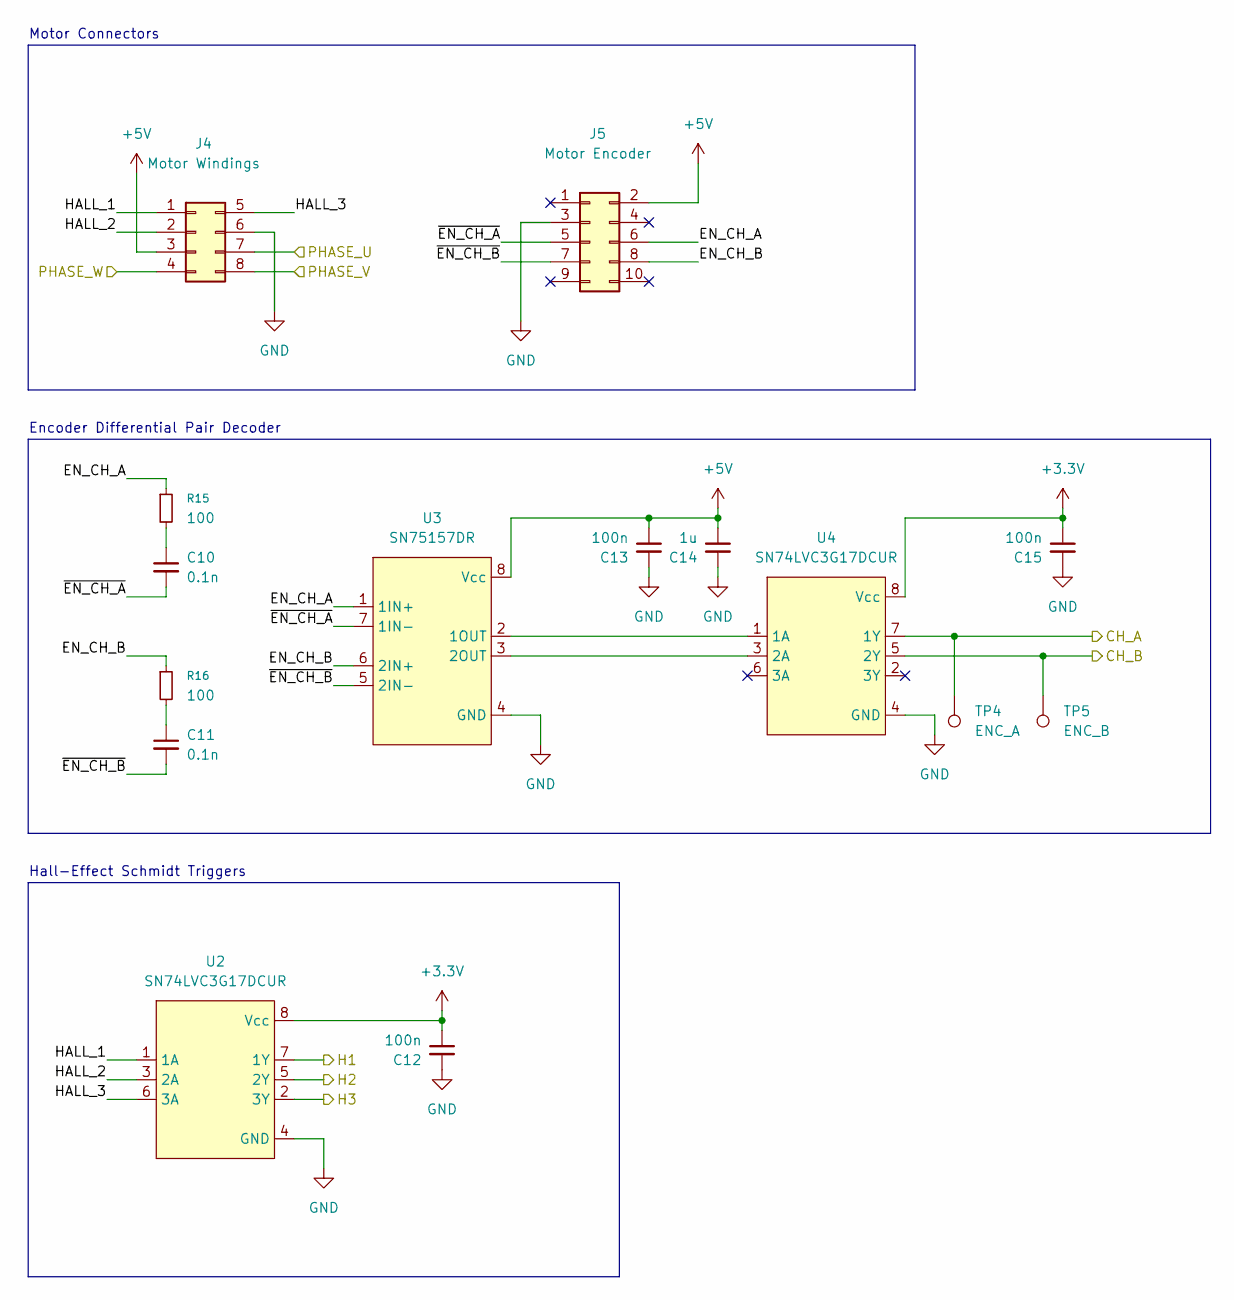
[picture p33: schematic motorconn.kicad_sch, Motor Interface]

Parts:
C10, C11: 0.1n; C_0603_1608Metric
C12, C13, C15: 100n; C_0603_1608Metric
C14: 1u; C_0603_1608Metric
J4: Motor Windings
J5: Motor Encoder
R15, R16: 100; R_0603_1608Metric
TP4: ENC_A; R_1206_3216Metric; Manufacturer P/N RCWCTE
TP5: ENC_B; R_1206_3216Metric; Manufacturer P/N RCWCTE
U2, U4: SN74LVC3G17DCUR; VSSOP-8_2.3x2mm_P0.5mm; Manufactuer P/N SN74LVC3G17DCUR
U3: SN75157DR; SOIC-8_3.9x4.9mm_P1.27mm; Manufacturer P/N SN75157DR

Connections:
+3.3V: C12.1, C15.1, U2.8 (Vcc), U4.8 (Vcc); also elsewhere on the board
+5V: C13.1, C14.1, J4.3, J5.2, U3.8 (Vcc); also elsewhere on the board
/ENC_A: TP4.1, U4.7 (1Y); also elsewhere on the board
/ENC_B: TP5.1, U4.5 (2Y); also elsewhere on the board
/H1: U2.7 (1Y); also elsewhere on the board
/H2: U2.5 (2Y); also elsewhere on the board
/H3: U2.2 (3Y); also elsewhere on the board
/Motor Interface/EN_CH_A: J5.6, R15.1, U3.1 (1IN+)
/Motor Interface/EN_CH_B: J5.8, R16.1, U3.6 (2IN+)
/Motor Interface/HALL_1: J4.1, U2.1 (1A)
/Motor Interface/HALL_2: J4.2, U2.3 (2A)
/Motor Interface/HALL_3: J4.5, U2.6 (3A)
/Motor Interface/~EN_CH_A: C10.2, J5.5, U3.7 (1IN-)
/Motor Interface/~EN_CH_B: C11.2, J5.7, U3.5 (2IN-)
GND: C12.2, C13.2, C14.2, C15.2, J4.6, J5.3, U2.4 (GND), U3.4 (GND), U4.4 (GND); also elsewhere on the board
unnamed: C10.1, R15.2
unnamed: C11.1, R16.2
unnamed: U3.2 (1OUT), U4.1 (1A)
unnamed: U3.3 (2OUT), U4.3 (2A)

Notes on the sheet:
Hall-Effect Schmidt Triggers
Encoder Differential Pair Decoder
Motor Connectors

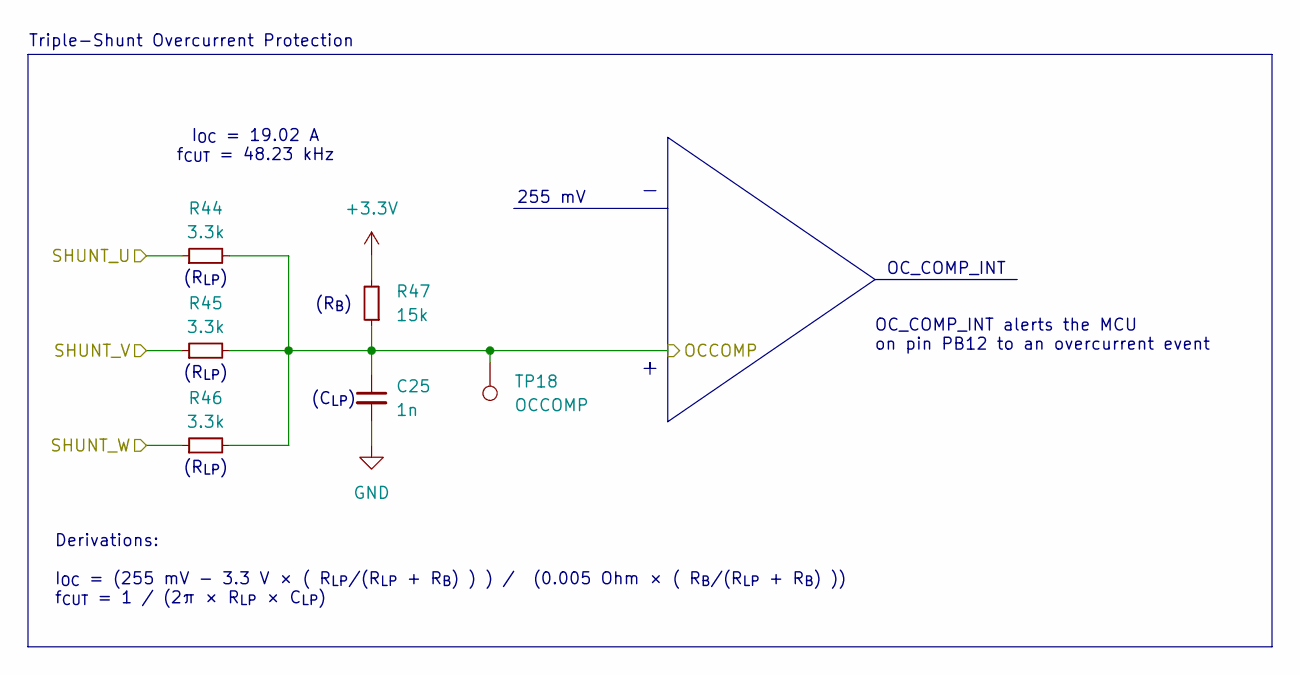
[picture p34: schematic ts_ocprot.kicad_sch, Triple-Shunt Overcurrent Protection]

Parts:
C25: 1n; C_0603_1608Metric
R44, R45, R46: 3.3k; R_0603_1608Metric
R47: 15k; R_0603_1608Metric
TP18: OCCOMP; R_1206_3216Metric; Manufacturer P/N RCWCTE

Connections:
+3.3V: R47.2; also elsewhere on the board
/OCCOMP: C25.1, R44.2, R45.2, R46.2, R47.1, TP18.1; also elsewhere on the board
/SHUNT_U: R44.1; also elsewhere on the board
/SHUNT_V: R45.1; also elsewhere on the board
/SHUNT_W: R46.1; also elsewhere on the board
GND: C25.2; also elsewhere on the board

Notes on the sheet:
(C_{LP})
(R_{LP})
(R_{B})
255 mV
Triple-Shunt Overcurrent Protection
Derivations: I_{OC} = (255 mV - 3.3 V × ( R_{LP}/(R_{LP} + R_{B}) ) ) / (0.005 Ohm × ( R_{B}/(R_{LP} + R_{B}) )) f_{CUT} = 1 / (2π × R_{LP} × C_{LP})
I_{OC} = 19.02 A f_{CUT} = 48.23 kHz
OC_COMP_INT alerts the MCU on pin PB12 to an overcurrent event
OC_COMP_INT

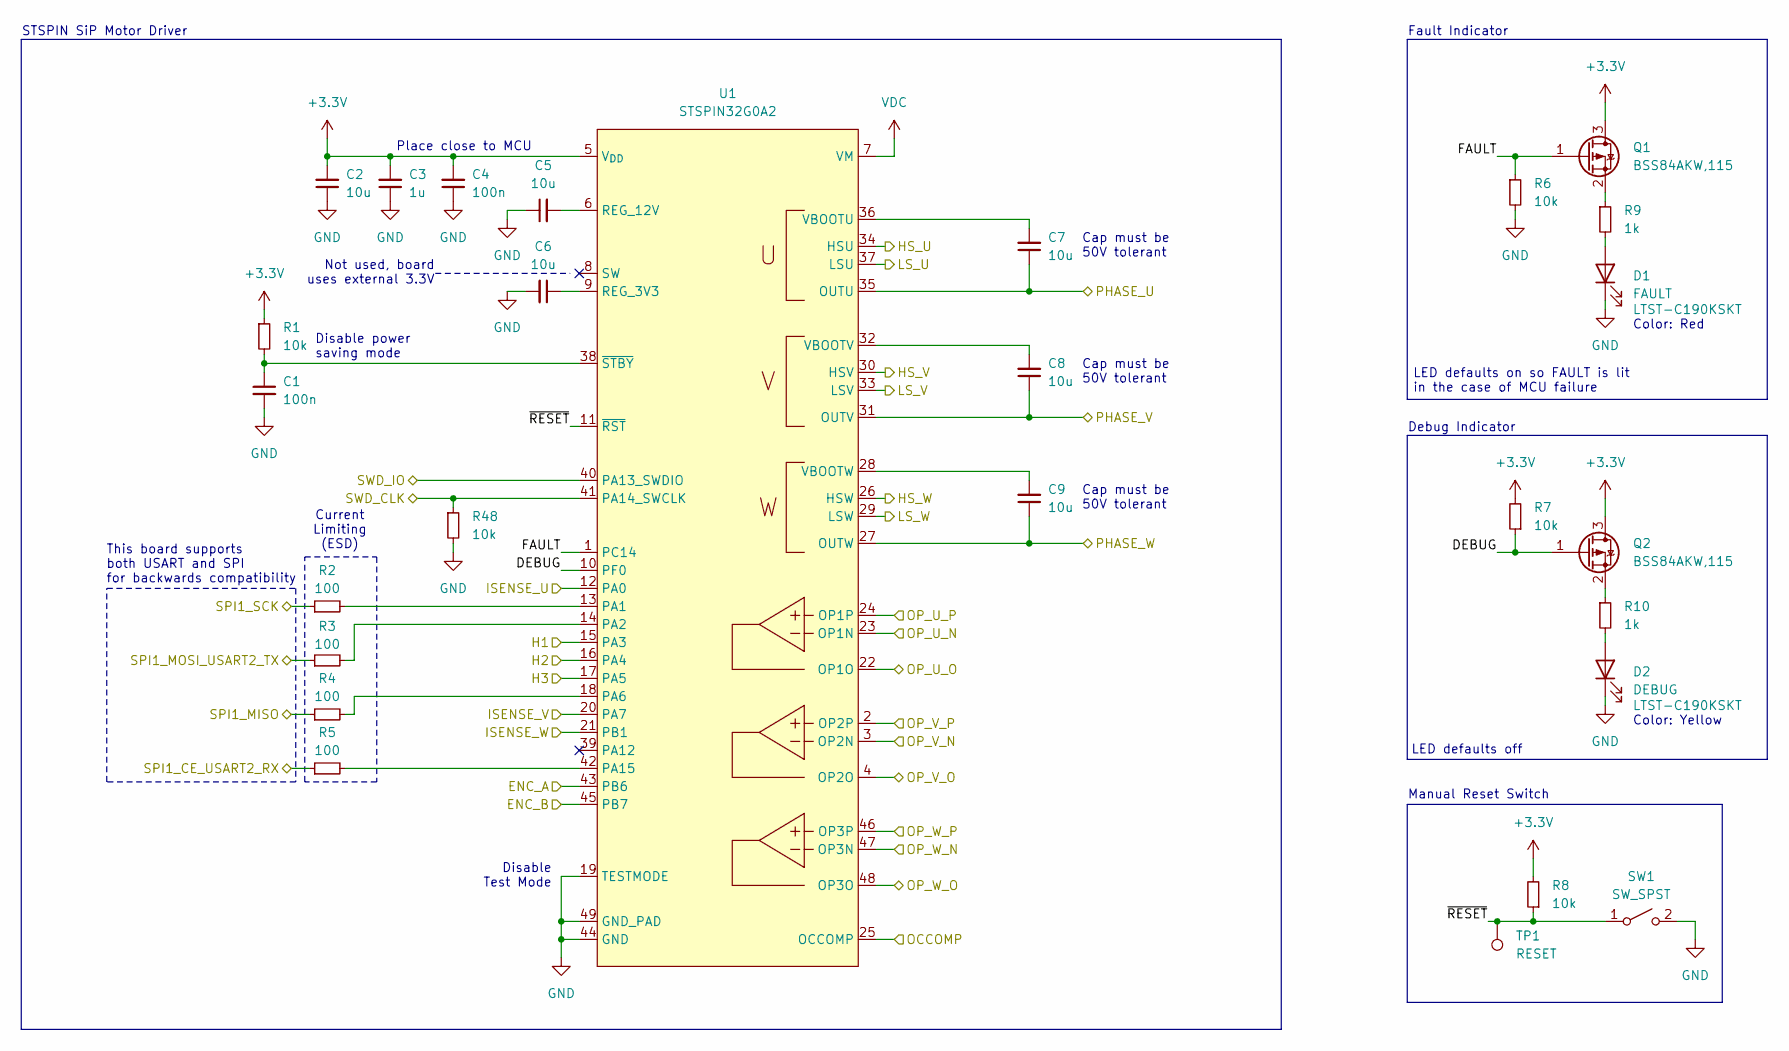
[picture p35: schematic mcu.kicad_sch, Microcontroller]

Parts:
C1, C4: 100n; C_0603_1608Metric
C2, C5, C6, C7, C8, C9: 10u; C_0603_1608Metric
C3: 1u; C_0603_1608Metric
D1: FAULT; LED_0603_1608Metric; Manufacturer P/N LTST-C190KSKT
D2: DEBUG; LED_0603_1608Metric; Manufacturer P/N LTST-C190KSKT
Q1, Q2: BSS84AKW,115; SOT-23; Manufacturer P/N BSS84AKW,115
R1, R6, R7, R8, R48: 10k; R_0603_1608Metric
R2, R3, R4, R5: 100; R_0402_1005Metric
R9, R10: 1k; R_0603_1608Metric
SW1: SW_SPST
TP1: RESET; R_1206_3216Metric; Manufacturer P/N RCWCTE
U1: STSPIN32G0A2; LQFP-48-1EP_7x7mm_P0.5mm_EP3.6x3.6mm; Manufacturer P/N STSPIN32G0A2

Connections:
+3.3V: C2.2, C3.2, C4.2, Q1.3 (D), Q2.3 (D), R1.1, R7.2, R8.2, U1.5 (V_{DD}); also elsewhere on the board
/ENC_A: U1.43 (PB6); also elsewhere on the board
/ENC_B: U1.45 (PB7); also elsewhere on the board
/H1: U1.15 (PA3); also elsewhere on the board
/H2: U1.16 (PA4); also elsewhere on the board
/H3: U1.17 (PA5); also elsewhere on the board
/Microcontroller/DEBUG: Q2.1 (G), R7.1, U1.10 (PF0)
/Microcontroller/FAULT: Q1.1 (G), R6.1, U1.1 (PC14)
/Microcontroller/HS_U: U1.34 (HSU); also elsewhere on the board
/Microcontroller/HS_V: U1.30 (HSV); also elsewhere on the board
/Microcontroller/HS_W: U1.26 (HSW); also elsewhere on the board
/Microcontroller/ISENSE_U: U1.12 (PA0), U1.22 (OP1O); also elsewhere on the board
/Microcontroller/ISENSE_V: U1.4 (OP2O), U1.20 (PA7); also elsewhere on the board
/Microcontroller/ISENSE_W: U1.21 (PB1), U1.48 (OP3O); also elsewhere on the board
/Microcontroller/LS_U: U1.37 (LSU); also elsewhere on the board
/Microcontroller/LS_V: U1.33 (LSV); also elsewhere on the board
/Microcontroller/LS_W: U1.29 (LSW); also elsewhere on the board
/Microcontroller/OP_U_N: U1.23 (OP1N); also elsewhere on the board
/Microcontroller/OP_U_P: U1.24 (OP1P); also elsewhere on the board
/Microcontroller/OP_V_N: U1.3 (OP2N); also elsewhere on the board
/Microcontroller/OP_V_P: U1.2 (OP2P); also elsewhere on the board
/Microcontroller/OP_W_N: U1.47 (OP3N); also elsewhere on the board
/Microcontroller/OP_W_P: U1.46 (OP3P); also elsewhere on the board
/Microcontroller/SPI1_CE_USART2_RX: R5.1; also elsewhere on the board
/Microcontroller/SPI1_MISO: R4.1; also elsewhere on the board
/Microcontroller/SPI1_MOSI_USART2_TX: R3.1; also elsewhere on the board
/Microcontroller/SPI1_SCK: R2.1; also elsewhere on the board
/Microcontroller/SWD_CLK: R48.1, U1.41 (PA14_SWCLK)
/Microcontroller/SWD_IO: U1.40 (PA13_SWDIO)
/Microcontroller/~RESET: R8.1, SW1.1 (A), TP1.1, U1.11 (~RST)
/OCCOMP: U1.25 (OCCOMP); also elsewhere on the board
/PHASE_U: C7.1, U1.35 (OUTU); also elsewhere on the board
/PHASE_V: C8.1, U1.31 (OUTV); also elsewhere on the board
/PHASE_W: C9.1, U1.27 (OUTW); also elsewhere on the board
GND: C1.2, C2.1, C3.1, C4.1, C5.1, C6.2, D1.1 (K), D2.1 (K), R6.2, R48.2, SW1.2 (B), U1.19 (TESTMODE), U1.44 (GND), U1.49 (GND_PAD); also elsewhere on the board
unnamed: D1.2 (A), R9.2
unnamed: D2.2 (A), R10.2
unnamed: Q1.2 (S), R9.1
unnamed: Q2.2 (S), R10.1
unnamed: R2.2, U1.13 (PA1)
unnamed: R3.2, U1.14 (PA2)
unnamed: R4.2, U1.18 (PA6)
unnamed: R5.2, U1.42 (PA15)
unnamed: C6.1, U1.9 (REG_3V3)
unnamed: C5.2, U1.6 (REG_12V)
unnamed: C7.2, U1.36 (VBOOTU)
unnamed: C8.2, U1.32 (VBOOTV)
unnamed: C9.2, U1.28 (VBOOTW)
unnamed: C1.1, R1.2, U1.38 (~STBY)
VDC: U1.7 (VM); also elsewhere on the board

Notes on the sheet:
Fault Indicator
Disable power saving mode
LED defaults on so FAULT is lit in the case of MCU failure
This board supports both USART and SPI for backwards compatibility
STSPIN SiP Motor Driver
Color: Red
Cap must be 50V tolerant
Place close to MCU
Current Limiting (ESD)
LED defaults off
Color: Yellow
Debug Indicator
Disable Test Mode
Manual Reset Switch
Not used, board uses external 3.3V

Board: 2 copper layers, 122 parts (0 on the bottom side), 74 nets, no tracks yet.

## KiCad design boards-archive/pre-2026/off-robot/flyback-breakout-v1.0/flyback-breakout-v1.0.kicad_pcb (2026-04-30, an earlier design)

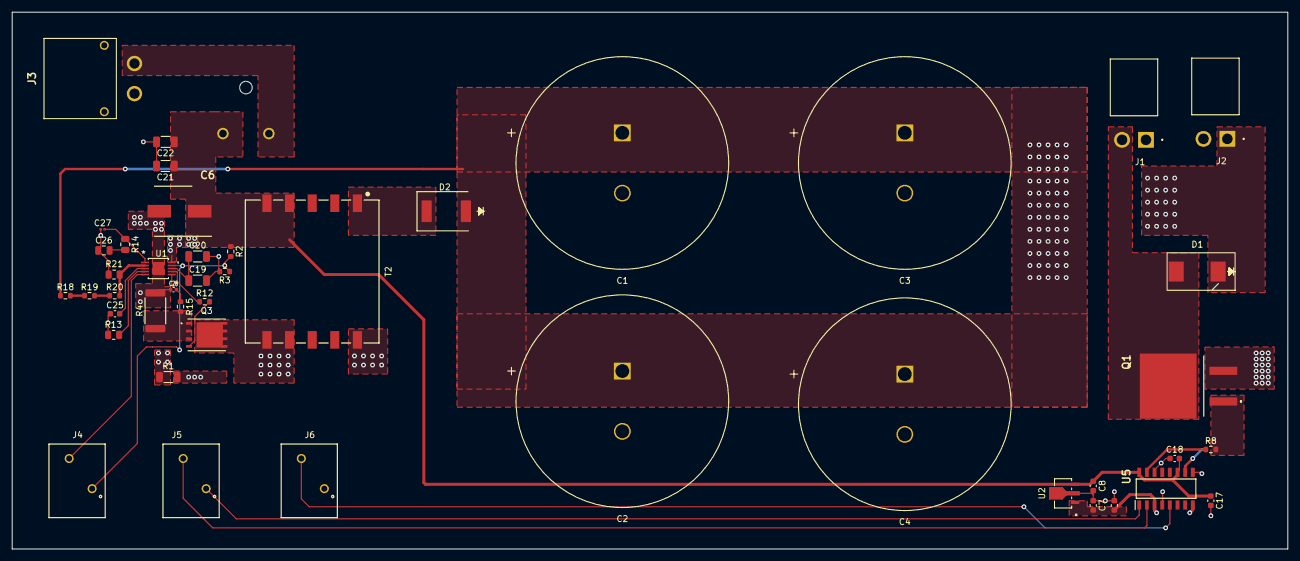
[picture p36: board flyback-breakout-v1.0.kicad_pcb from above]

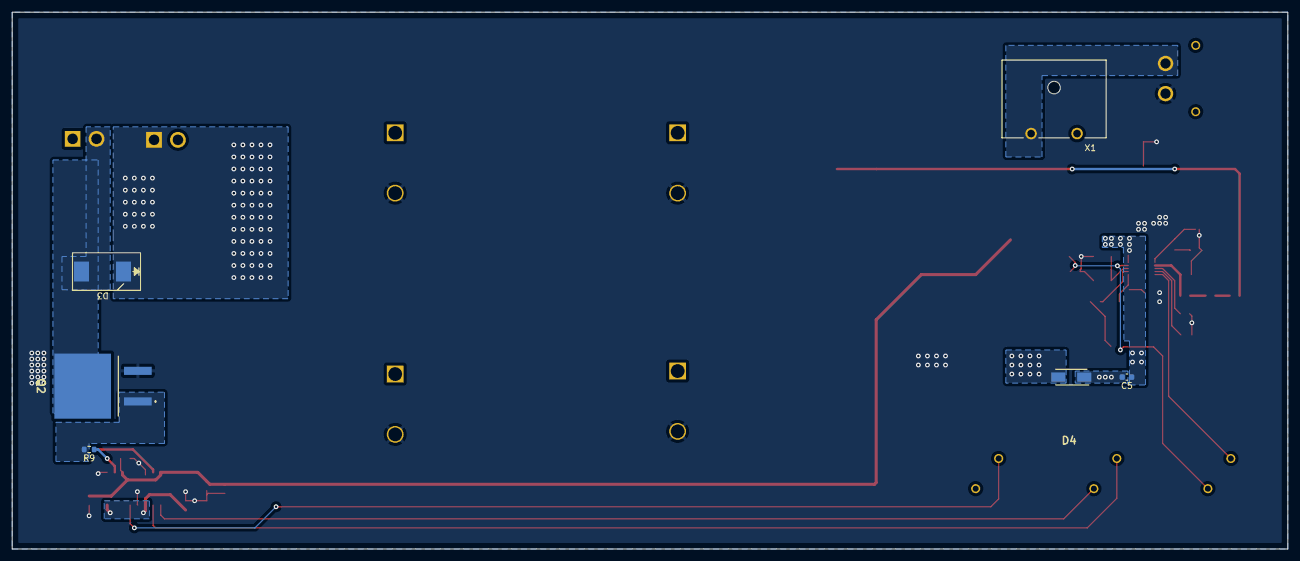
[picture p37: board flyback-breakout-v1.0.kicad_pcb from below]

Board: 2 copper layers, 211.5 x 89.0 mm, 51 parts (6 on the bottom side), 31 nets.

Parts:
C1, C2, C3, C4: 1000uF; CHEMI-VSN_A50
C5, C7, C8, C15, C17, C18, C25: 0.1uF; C_0603_1608Metric
C6: HHXC500ARA470MHA0G; CAPAE830X1050N
C19, C20, C21, C22: 10uF; C_1206_3216Metric
C26: 22nF; C_0805_2012Metric
C27: 100pF; C_0201_0603Metric
C28: 10nF; C_0402_1005Metric
D1, D3: MURS460C; SMC
D2: US3M; P27_DO-214AB_SMC
D4: SBR1U150SA-13; DIOM5226X230N
J1, J2: B2PS-VH(LF)(SN); JST_B2PS-VH
J3: XT30PW-F; XT30PWF
J4, J5, J6: 691412320002
Q1, Q2: IKB40N65ES5ATMA1; BTS141TCBUMA1
Q3: SIR880BDP-T1-RE3; POWERPAK_SO-8_SINGLE_VIS
R1: 4.22k; R_1206_3216Metric
R2, R18, R19: 100k; R_0603_1608Metric
R3: 10k; R_0603_1608Metric
R4: 22m; R_2512_6332Metric
R8, R9, R12: 4.7; R_0603_1608Metric
R13: 442k; R_0805_2012Metric
R14: 6.8k; R_0805_2012Metric
R15: 22; R_0603_1608Metric
R20: 40k; R_0603_1608Metric
R21: 1.54k; R_0805_2012Metric
T2: 750032052; WE-FB3751_EFD20
U1: LT3757AIMSE-TRPBF; MSOP-10_MSE_LIT
U2: AS78L05RTR-E1; SOT89_B8D_DIO
U5: 2EDB8259FXUMA1; SOIC127P600X175-16N
X1: 01530007Z; FUSE_01530007Z

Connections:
+5V: C7.1, C15.1, U2.1 (OUTPUT), U5.3 (VDDI_1), U5.8 (VDDI_2)
/CHIP_IN: J5.2, U5.2 (INB)
/DIS: J6.2, U5.5 (DIS)
/KICK_IN: J5.1, U5.1 (INA)
/SYNC: J4.2, U1.5 (SYNC)
/discharge_breakout/CHIP_GATE: Q2.1 (G), R9.2
/discharge_breakout/CHIP_OUT: R9.1, U5.10 (OUTB)
/discharge_breakout/KICK_GATE: Q1.1 (G), R8.2
/discharge_breakout/KICK_OUT: R8.1, U5.15 (OUTA)
/flyback_breakout/DRAIN: D4.2 (A), Q3.5, Q3.6, Q3.7, Q3.8, T2.6, T2.7
/flyback_breakout/FBX: R20.2, R21.1, U1.2 (FBX)
/flyback_breakout/INTVCC: C19.1, C20.1, U1.8 (INTVCC)
/flyback_breakout/SENSE: C28.2, R15.2, U1.6 (SENSE)
/flyback_breakout/SOURCE: Q3.1, Q3.2, Q3.3, R4.1, R15.1
/~SHDN: J4.1, R2.2, R3.1, U1.9 (*SHDN/UVLO)
GND: C1.2, C2.2, C3.2, C4.2, C6.2 (-), C7.2, C8.2, C15.2, C17.2, C18.2, C19.2, C20.2, C21.2, C22.2, C25.1, C26.1, C27.1, C28.1, J3.1, Q1.3 (E), Q2.3 (E), R3.2, R4.2, R13.2, R21.2, T2.10, U1.11 (EPAD), U2.2 (GND), U5.4 (GNDI), U5.9 (GNDB), U5.14 (GNDA)
HV: C1.1, C2.1, C3.1, C4.1, D1.1 (K), D2.2 (C), D3.1 (K), J1.1, J2.1, R18.1
unnamed: C26.2, R14.2
unnamed: D1.2 (A), J1.2, Q1.2 (C)
unnamed: D2.1 (A), T2.1
unnamed: D3.2 (A), J2.2, Q2.2 (C)
unnamed: C5.2, D4.1 (K), R1.2
unnamed: J3.2, X1.2
unnamed: Q3.4, R12.2
unnamed: R18.2, R19.1
unnamed: R19.2, R20.1
unnamed: R12.1, U1.7 (GATE)
unnamed: R13.1, U1.4 (RT)
unnamed: C25.2, U1.3 (SS)
unnamed: C27.2, R14.1, U1.1 (VC)
VDC: C5.1, C6.1 (+), C8.1, C17.1, C18.1, C21.1, C22.1, R1.1, R2.1, T2.4, T2.5, U1.10 (VIN), U2.3 (INPUT), U5.11 (VDDB), U5.16 (VDDA), X1.1

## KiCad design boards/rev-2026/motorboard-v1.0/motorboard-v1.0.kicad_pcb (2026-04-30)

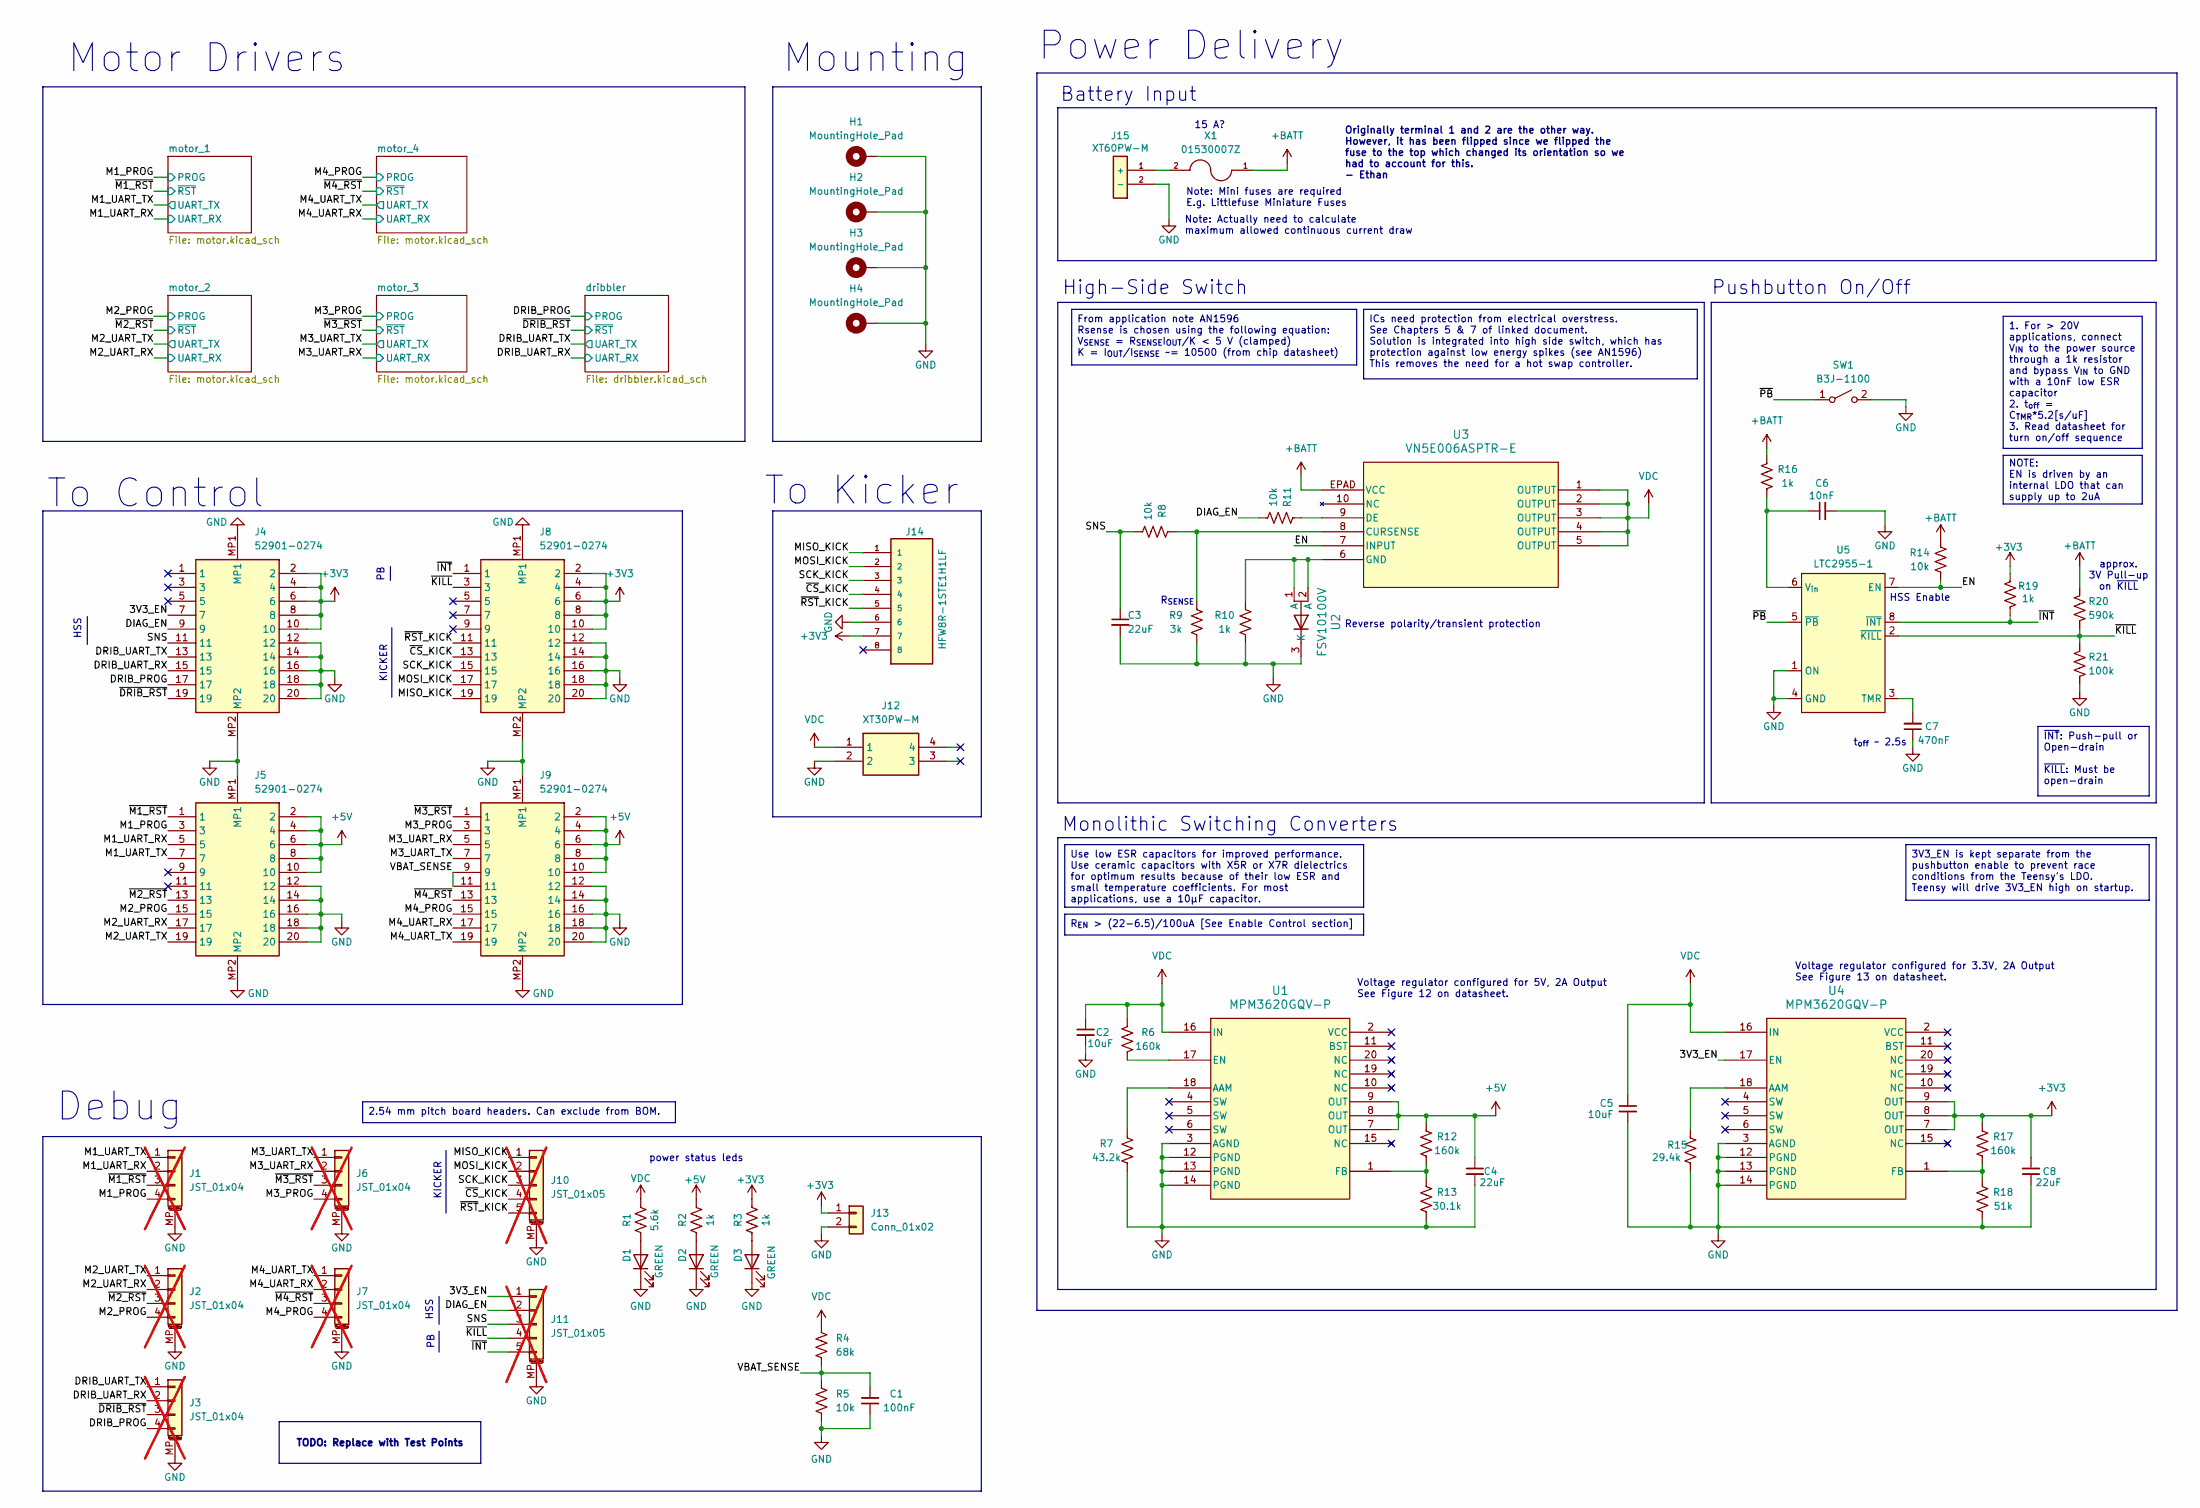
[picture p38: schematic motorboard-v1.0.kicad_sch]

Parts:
C1: 100nF; C_0603_1608Metric
C2, C5: 10uF; C_1206_3216Metric
C3, C4, C8: 22uF; C_1206_3216Metric
C6: 10nF; C_0603_1608Metric
C7: 470nF; C_0603_1608Metric
D1, D2, D3: GREEN; D_0603_1608Metric
H1, H2, H3, H4: MountingHole_Pad; MountingHole_3.7mm_Pad
J1, J2, J3, J6, J7: JST_01x04; JST_SH_BM04B-SRSS-TB_1x04-1MP_P1.00mm_Vertical; not fitted
J4, J5, J8, J9: 52901-0274; 529010274; Manufacturer_Part_Number 52901-0274; Mouser Part Number 538-52901-0274
J10, J11: JST_01x05; JST_SH_BM05B-SRSS-TB_1x05-1MP_P1.00mm_Vertical; not fitted
J12: XT30PW-M; XT30PWM; Manufacturer P/N XT30PW-M
J13: Conn_01x02; PinHeader_1x02_P2.54mm_Vertical
J14: HFW8R-1STE1H1LF; AMPHENOL_HFW8R-1STE1H1LF; PARTREV B
J15: XT60PW-M; XT60PWM; Manufacturer P/N XT60PW-M
R1: 5.6k; R_0603_1608Metric
R2, R3, R10, R16, R19: 1k; R_0603_1608Metric
R4: 68k; R_0603_1608Metric
R5, R8, R11, R14: 10k; R_0603_1608Metric
R6, R12, R17: 160k; R_0603_1608Metric
R7: 43.2k; R_0603_1608Metric
R9: 3k; R_0603_1608Metric
R13: 30.1k; R_0603_1608Metric
R15: 29.4k; R_0603_1608Metric
R18: 51k; R_0603_1608Metric
R20: 590k; R_0603_1608Metric
R21: 100k; R_0603_1608Metric
SW1: B3J-1100; B3J-1000
U1, U4: MPM3620GQV-P; MPM3620GQVP; Manufacturer P/N MPM3620GQV-P
U2: FSV10100V; DIO_10100V_ONS; Manufacturer P/N FSV10100V
U3: VN5E006ASPTR-E; SO_E006ASP-E_STM; Manufacturer P/N VN5E006ASPTR-E
U5: LTC2955-1; SOT65P280X100-8N; Manufacturer P/N LTC2955CTS8-1#TRMPBF
X1: 01530007Z; FUSE_01530007Z; Manufacturer P/N 01530007Z

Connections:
+3V3: C8.1, J4.2, J4.4, J4.6, J4.8, J4.10, J8.2, J8.4, J8.6, J8.8, J8.10, J13.1, J14.7, R3.2, R17.2, R19.2, U4.7 (OUT), U4.8 (OUT), U4.9 (OUT); also elsewhere on the board
+5V: C4.1, J5.2, J5.4, J5.6, J5.8, J5.10, J9.2, J9.4, J9.6, J9.8, J9.10, R2.2, R12.2, U1.7 (OUT), U1.8 (OUT), U1.9 (OUT); also elsewhere on the board
+BATT: R14.2, R16.2, R20.2, U3.EPAD (VCC), X1.1
/3V3_EN: J4.7, J11.1, U4.17 (EN)
/DIAG_EN: J4.9, J11.2, R11.1
/DRIB_PROG: J3.4, J4.17; also elsewhere on the board
/DRIB_UART_RX: J3.2, J4.15; also elsewhere on the board
/DRIB_UART_TX: J3.1, J4.13; also elsewhere on the board
/EN: R14.1, U3.7 (INPUT), U5.7 (EN)
/M1_PROG: J1.4, J5.3; also elsewhere on the board
/M1_UART_RX: J1.2, J5.5; also elsewhere on the board
/M1_UART_TX: J1.1, J5.7; also elsewhere on the board
/M2_PROG: J2.4, J5.15; also elsewhere on the board
/M2_UART_RX: J2.2, J5.17; also elsewhere on the board
/M2_UART_TX: J2.1, J5.19; also elsewhere on the board
/M3_PROG: J6.4, J9.3; also elsewhere on the board
/M3_UART_RX: J6.2, J9.5; also elsewhere on the board
/M3_UART_TX: J6.1, J9.7; also elsewhere on the board
/M4_PROG: J7.4, J9.15; also elsewhere on the board
/M4_UART_RX: J7.2, J9.17; also elsewhere on the board
/M4_UART_TX: J7.1, J9.19; also elsewhere on the board
/MISO_KICK: J8.19, J10.1, J14.1
/MOSI_KICK: J8.17, J10.2, J14.2
/SCK_KICK: J8.15, J10.3, J14.3
/SNS: C3.1, J4.11, J11.3, R8.1
/VBAT_SENSE: C1.2, J9.9, J9.11, R4.2, R5.1
/~CS_KICK: J8.13, J10.4, J14.4
/~DRIB_RST: J3.3, J4.19; also elsewhere on the board
/~INT: J8.1, J11.5, R19.1, U5.8 (~INT)
/~KILL: J8.3, J11.4, R20.1, R21.2, U5.2 (~KILL)
/~M1_RST: J1.3, J5.1; also elsewhere on the board
/~M2_RST: J2.3, J5.13; also elsewhere on the board
/~M3_RST: J6.3, J9.1; also elsewhere on the board
/~M4_RST: J7.3, J9.13; also elsewhere on the board
/~PB: SW1.1 (A), U5.5 (~PB)
/~RST_KICK: J8.11, J10.5, J14.5
GND: C1.1, C2.2, C3.2, C4.2, C5.2, C6.2, C7.1, C8.2, D1.1 (K), D2.1 (K), D3.1 (K), H1.1 (1_1), H2.1 (1_1), H3.1 (1_1), H4.1 (1_1), J1.MP (MountPin), J2.MP (MountPin), J3.MP (MountPin), J4.12, J4.14, J4.16, J4.18, J4.20, J4.MP1, J4.MP2, J5.12, J5.14, J5.16, J5.18, J5.20, J5.MP1, J5.MP2, J6.MP (MountPin), J7.MP (MountPin), J8.12, J8.14, J8.16, J8.18, J8.20, J8.MP1, J8.MP2, J9.12, J9.14, J9.16, J9.18, J9.20, J9.MP1, J9.MP2, J10.MP (MountPin), J11.MP (MountPin), J12.2, J13.2, J14.6, J15.2 (-), R5.2, R7.1, R9.1, R10.1, R13.1, R15.1, R18.1, R21.1, SW1.2 (B), U1.3 (AGND), U1.12 (PGND), U1.13 (PGND), U1.14 (PGND), U2.3 (K), U4.3 (AGND), U4.12 (PGND), U4.13 (PGND), U4.14 (PGND), U5.1 (ON), U5.4 (GND); also elsewhere on the board
unnamed: D1.2 (A), R1.1
unnamed: D2.2 (A), R2.1
unnamed: D3.2 (A), R3.1
unnamed: J15.1 (+), X1.2
unnamed: R7.2, U1.18 (AAM)
unnamed: R6.1, U1.17 (EN)
unnamed: R12.1, R13.2, U1.1 (FB)
unnamed: R8.2, R9.2, U3.8 (CURSENSE)
unnamed: R11.2, U3.9 (DE)
unnamed: R10.2, U2.1 (A), U2.2 (A), U3.6 (GND)
unnamed: R15.2, U4.18 (AAM)
unnamed: R17.1, R18.2, U4.1 (FB)
unnamed: C7.2, U5.3 (TMR)
unnamed: C6.1, R16.1, U5.6 (V_{in})
VDC: C2.1, C5.1, J12.1, R1.2, R4.1, R6.2, U1.16 (IN), U3.1 (OUTPUT), U3.2 (OUTPUT), U3.3 (OUTPUT), U3.4 (OUTPUT), U3.5 (OUTPUT), U4.16 (IN); also elsewhere on the board

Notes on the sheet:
Mounting
HSS
Reverse polarity/transient protection
Debug
KICKER
Battery Input
Voltage regulator configured for 3.3V, 2A Output See Figure 13 on datasheet.
Originally terminal 1 and 2 are the other way. However, it has been flipped since we flipped the fuse to the top which changed its orientation so we had to account for this. - Ethan
HSS Enable
Power Delivery
power status leds
15 A?
Note: Mini fuses are required E.g. Littlefuse Miniature Fuses
To Kicker
Monolithic Switching Converters
High-Side Switch
R_{SENSE}
Note: Actually need to calculate maximum allowed continuous current draw
Voltage regulator configured for 5V, 2A Output See Figure 12 on datasheet.
approx. 3V Pull-up on ~{KILL}
Pushbutton On/Off
Motor Drivers
To Control
t_{off} ~ 2.5s
~{INT}: Push-pull or Open-drain ~{KILL}: Must be open-drain
R_{EN} > (22-6.5)/100uA [See Enable Control section]
1. For > 20V applications, connect V_{IN} to the power source through a 1k resistor and bypass V_{IN} to GND with a 10nF low ESR capacitor 2. t_{off} = C_{TMR}*5.2[s/uF] 3. Read datasheet for turn on/off sequence
TODO: Replace with Test Points
From application note AN1596 Rsense is chosen using the following equation: V_{SENSE} = R_{SENSE}I_{OUT}/K < 5 V (clamped) K = I_{OUT}/I_{SENSE} ~= 10500 (from chip datasheet)
NOTE: EN is driven by an internal LDO that can supply up to 2uA
Use low ESR capacitors for improved performance. Use ceramic capacitors with X5R or X7R dielectrics for optimum results because of their low ESR and small temperature coefficients. For most applications, use a 10μF capacitor.
3V3_EN is kept separate from the pushbutton enable to prevent race conditions from the Teensy's LDO. Teensy will drive 3V3_EN high on startup.
ICs need protection from electrical overstress. See Chapters 5 & 7 of linked document. Solution is integrated into high side switch, which has protection against low energy spikes (see AN1596) This removes the need for a hot swap controller.
2.54 mm pitch board headers. Can exclude from BOM.

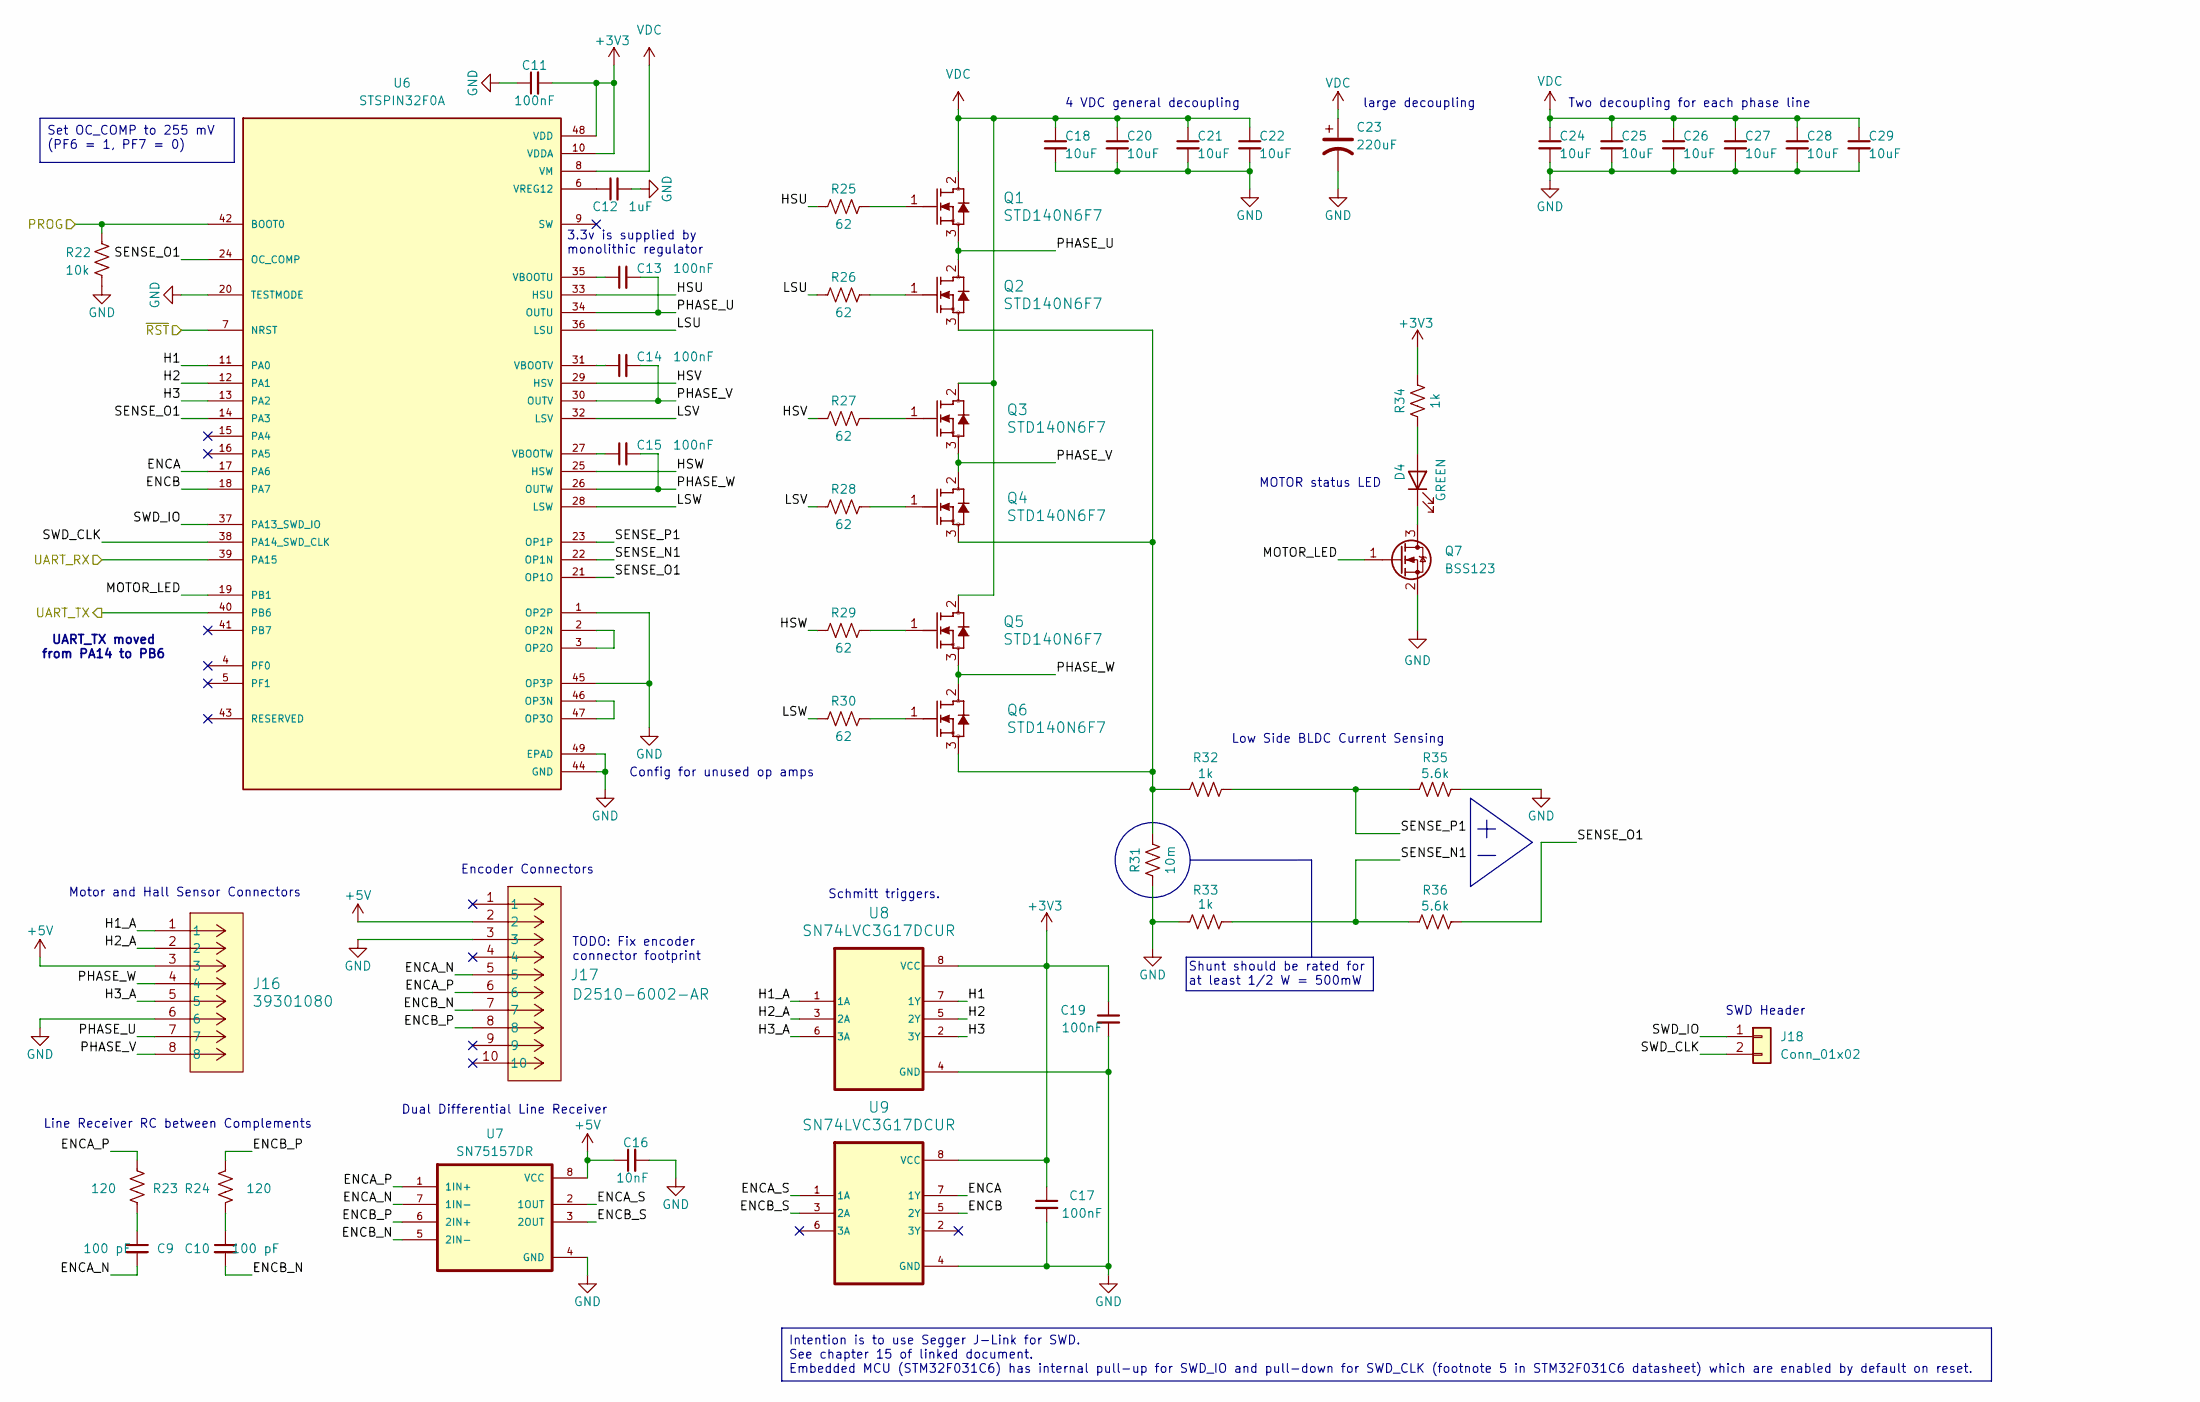
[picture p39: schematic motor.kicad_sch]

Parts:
C9, C10: 100 pF; C_0603_1608Metric
C11, C13, C14, C15, C17, C19: 100nF; C_0603_1608Metric
C12: 1uF; C_0603_1608Metric
C16: 10nF; C_1206_3216Metric
C18, C20, C21, C22, C24, C25, C26, C27, C28, C29: 10uF; C_1206_3216Metric
C23: 220uF; CP_Elec_6.3x7.7
D4: GREEN; D_0603_1608Metric
J16: 39301080; Molex_Mini-Fit_Jr_5566-08A_2x04_P4.20mm_Vertical; Manufacturer P/N 0039301080
J17: D2510-6002-AR; CONN_6002RB_3MM; Manufacturer P/N MHC10E-ND
J18: Conn_01x02; PinHeader_1x02_P2.54mm_Vertical
Q1, Q2, Q3, Q4, Q5, Q6: STD140N6F7; DPAKTO-252_A2_STM; Manufacturer P/N STD140N6F7
Q7: BSS123; SOT-23
R22: 10k; R_0603_1608Metric
R23, R24: 120; R_0603_1608Metric
R25, R26, R27, R28, R29, R30: 62; R_0603_1608Metric
R31: 10m; R_1206_3216Metric
R32, R33, R34: 1k; R_0603_1608Metric
R35, R36: 5.6k; R_0603_1608Metric
U6: STSPIN32F0A; IC_STSPIN32F0A; Manufacturer P/N STSPIN32F0A
U7: SN75157DR; SOIC127P599X175-8N
U8, U9: SN74LVC3G17DCUR; SOP50P310X90-8N; Manufacturer P/N SN74LVC3G17DCTR

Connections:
+3V3: C11.2, C17.1, C19.1, R34.2, U6.10 (VDDA), U6.48 (VDD), U8.8 (VCC), U9.8 (VCC); also elsewhere on the board
+5V: C16.1, J16.3, J17.2, U7.8 (VCC); also elsewhere on the board
/M1_PROG: R22.1, U6.42 (BOOT0); also elsewhere on the board
/M1_UART_RX: U6.39 (PA15); also elsewhere on the board
/M1_UART_TX: U6.40 (PB6); also elsewhere on the board
/motor_1/ENCA: U6.17 (PA6), U9.7 (1Y)
/motor_1/ENCA_N: C9.2, J17.5, U7.7 (1IN-)
/motor_1/ENCA_P: J17.6, R23.2, U7.1 (1IN+)
/motor_1/ENCA_S: U7.2 (1OUT), U9.1 (1A)
/motor_1/ENCB: U6.18 (PA7), U9.5 (2Y)
/motor_1/ENCB_N: C10.2, J17.7, U7.5 (2IN-)
/motor_1/ENCB_P: J17.8, R24.2, U7.6 (2IN+)
/motor_1/ENCB_S: U7.3 (2OUT), U9.3 (2A)
/motor_1/H1: U6.11 (PA0), U8.7 (1Y)
/motor_1/H1_A: J16.1, U8.1 (1A)
/motor_1/H2: U6.12 (PA1), U8.5 (2Y)
/motor_1/H2_A: J16.2, U8.3 (2A)
/motor_1/H3: U6.13 (PA2), U8.2 (3Y)
/motor_1/H3_A: J16.5, U8.6 (3A)
/motor_1/HSU: R25.1, U6.33 (HSU)
/motor_1/HSV: R27.1, U6.29 (HSV)
/motor_1/HSW: R29.1, U6.25 (HSW)
/motor_1/LSU: R26.1, U6.36 (LSU)
/motor_1/LSV: R28.1, U6.32 (LSV)
/motor_1/LSW: R30.1, U6.28 (LSW)
/motor_1/MOTOR_LED: Q7.1 (G), U6.19 (PB1)
/motor_1/PHASE_U: C13.2, J16.7, Q1.3 (S), Q2.2 (D), U6.34 (OUTU)
/motor_1/PHASE_V: C14.2, J16.8, Q3.3 (S), Q4.2 (D), U6.30 (OUTV)
/motor_1/PHASE_W: C15.2, J16.4, Q5.3 (S), Q6.2 (D), U6.26 (OUTW)
/motor_1/SENSE_N1: R33.2, R36.1, U6.22 (OP1N)
/motor_1/SENSE_O1: R36.2, U6.14 (PA3), U6.21 (OP1O), U6.24 (OC_COMP)
/motor_1/SENSE_P1: R32.2, R35.1, U6.23 (OP1P)
/motor_1/SWD_CLK: J18.2, U6.38 (PA14_SWD_CLK)
/motor_1/SWD_IO: J18.1, U6.37 (PA13_SWD_IO)
/~M1_RST: U6.7 (NRST); also elsewhere on the board
GND: C11.1, C12.2, C16.2, C17.2, C18.2, C19.2, C20.2, C21.2, C22.2, C23.2, C24.2, C25.2, C26.2, C27.2, C28.2, C29.2, J16.6, J17.3, Q7.2 (S), R22.2, R31.1, R33.1, R35.2, U6.1 (OP2P), U6.20 (TESTMODE), U6.44 (GND), U6.45 (OP3P), U6.49 (EPAD), U7.4 (GND), U8.4 (GND), U9.4 (GND); also elsewhere on the board
unnamed: C9.1, R23.1
unnamed: C10.1, R24.1
unnamed: D4.2 (A), R34.1
unnamed: D4.1 (K), Q7.3 (D)
unnamed: Q1.1 (G), R25.2
unnamed: Q2.1 (G), R26.2
unnamed: Q2.3 (S), Q4.3 (S), Q6.3 (S), R31.2, R32.1
unnamed: Q3.1 (G), R27.2
unnamed: Q4.1 (G), R28.2
unnamed: Q5.1 (G), R29.2
unnamed: Q6.1 (G), R30.2
unnamed: U6.2 (OP2N), U6.3 (OP2O)
unnamed: U6.46 (OP3N), U6.47 (OP3O)
unnamed: C13.1, U6.35 (VBOOTU)
unnamed: C14.1, U6.31 (VBOOTV)
unnamed: C15.1, U6.27 (VBOOTW)
unnamed: C12.1, U6.6 (VREG12)
VDC: C18.1, C20.1, C21.1, C22.1, C23.1, C24.1, C25.1, C26.1, C27.1, C28.1, C29.1, Q1.2 (D), Q3.2 (D), Q5.2 (D), U6.8 (VM); also elsewhere on the board

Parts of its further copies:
C30, C31, C51, C52, C72, C73: 100 pF; C_0603_1608Metric
C32, C34, C35, C36, C38, C40, C53, C55, C56, C57, C59, C61, C74, C76, C77, C78, C80, C82: 100nF; C_0603_1608Metric
C33, C54, C75: 1uF; C_0603_1608Metric
C37, C58, C79: 10nF; C_1206_3216Metric
C39, C41, C42, C43, C45, C46, C47, C48, C49, C50, C60, C62, C63, C64, C66, C67, C68, C69, C70, C71, C81, C83, C84, C85, C87, C88, C89, C90, C91, C92: 10uF; C_1206_3216Metric
C44, C65, C86: 220uF; CP_Elec_6.3x7.7
D5, D6, D7: GREEN; D_0603_1608Metric
J19, J22, J25: 39301080; Molex_Mini-Fit_Jr_5566-08A_2x04_P4.20mm_Vertical; Manufacturer P/N 0039301080
J20, J23, J26: D2510-6002-AR; CONN_6002RB_3MM; Manufacturer P/N MHC10E-ND
J21, J24, J27: Conn_01x02; PinHeader_1x02_P2.54mm_Vertical
Q8, Q9, Q10, Q11, Q12, Q13, Q15, Q16, Q17, Q18, Q19, Q20, Q22, Q23, Q24, Q25, Q26, Q27: STD140N6F7; DPAKTO-252_A2_STM; Manufacturer P/N STD140N6F7
Q14, Q21, Q28: BSS123; SOT-23
R37, R52, R67: 10k; R_0603_1608Metric
R38, R39, R53, R54, R68, R69: 120; R_0603_1608Metric
R40, R41, R42, R43, R44, R45, R55, R56, R57, R58, R59, R60, R70, R71, R72, R73, R74, R75: 62; R_0603_1608Metric
R46, R61, R76: 10m; R_1206_3216Metric
R47, R48, R49, R62, R63, R64, R77, R78, R79: 1k; R_0603_1608Metric
R50, R51, R65, R66, R80, R81: 5.6k; R_0603_1608Metric
U10, U14, U18: STSPIN32F0A; IC_STSPIN32F0A; Manufacturer P/N STSPIN32F0A
U11, U15, U19: SN75157DR; SOIC127P599X175-8N
U12, U13, U16, U17, U20, U21: SN74LVC3G17DCUR; SOP50P310X90-8N; Manufacturer P/N SN74LVC3G17DCTR

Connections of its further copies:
+3V3: C32.2, C38.1, C40.1, C53.2, C59.1, C61.1, C74.2, C80.1, C82.1, R49.2, R64.2, R79.2, U10.10 (VDDA), U10.48 (VDD), U12.8 (VCC), U13.8 (VCC), U14.10 (VDDA), U14.48 (VDD), U16.8 (VCC), U17.8 (VCC), U18.10 (VDDA), U18.48 (VDD), U20.8 (VCC), U21.8 (VCC); also elsewhere on the board
+5V: C37.1, C58.1, C79.1, J19.3, J20.2, J22.3, J23.2, J25.3, J26.2, U11.8 (VCC), U15.8 (VCC), U19.8 (VCC); also elsewhere on the board
/M2_PROG: R37.1, U10.42 (BOOT0); also elsewhere on the board
/M2_UART_RX: U10.39 (PA15); also elsewhere on the board
/M2_UART_TX: U10.40 (PB6); also elsewhere on the board
/M3_PROG: R52.1, U14.42 (BOOT0); also elsewhere on the board
/M3_UART_RX: U14.39 (PA15); also elsewhere on the board
/M3_UART_TX: U14.40 (PB6); also elsewhere on the board
/M4_PROG: R67.1, U18.42 (BOOT0); also elsewhere on the board
/M4_UART_RX: U18.39 (PA15); also elsewhere on the board
/M4_UART_TX: U18.40 (PB6); also elsewhere on the board
/motor_2/ENCA: U10.17 (PA6), U13.7 (1Y)
/motor_2/ENCA_N: C30.2, J20.5, U11.7 (1IN-)
/motor_2/ENCA_P: J20.6, R38.2, U11.1 (1IN+)
/motor_2/ENCA_S: U11.2 (1OUT), U13.1 (1A)
/motor_2/ENCB: U10.18 (PA7), U13.5 (2Y)
/motor_2/ENCB_N: C31.2, J20.7, U11.5 (2IN-)
/motor_2/ENCB_P: J20.8, R39.2, U11.6 (2IN+)
/motor_2/ENCB_S: U11.3 (2OUT), U13.3 (2A)
/motor_2/H1: U10.11 (PA0), U12.7 (1Y)
/motor_2/H1_A: J19.1, U12.1 (1A)
/motor_2/H2: U10.12 (PA1), U12.5 (2Y)
/motor_2/H2_A: J19.2, U12.3 (2A)
/motor_2/H3: U10.13 (PA2), U12.2 (3Y)
/motor_2/H3_A: J19.5, U12.6 (3A)
/motor_2/HSU: R40.1, U10.33 (HSU)
/motor_2/HSV: R42.1, U10.29 (HSV)
/motor_2/HSW: R44.1, U10.25 (HSW)
/motor_2/LSU: R41.1, U10.36 (LSU)
/motor_2/LSV: R43.1, U10.32 (LSV)
/motor_2/LSW: R45.1, U10.28 (LSW)
/motor_2/MOTOR_LED: Q14.1 (G), U10.19 (PB1)
/motor_2/PHASE_U: C34.2, J19.7, Q8.3 (S), Q9.2 (D), U10.34 (OUTU)
/motor_2/PHASE_V: C35.2, J19.8, Q10.3 (S), Q11.2 (D), U10.30 (OUTV)
/motor_2/PHASE_W: C36.2, J19.4, Q12.3 (S), Q13.2 (D), U10.26 (OUTW)
/motor_2/SENSE_N1: R48.2, R51.1, U10.22 (OP1N)
/motor_2/SENSE_O1: R51.2, U10.14 (PA3), U10.21 (OP1O), U10.24 (OC_COMP)
/motor_2/SENSE_P1: R47.2, R50.1, U10.23 (OP1P)
/motor_2/SWD_CLK: J21.2, U10.38 (PA14_SWD_CLK)
/motor_2/SWD_IO: J21.1, U10.37 (PA13_SWD_IO)
/motor_3/ENCA: U14.17 (PA6), U17.7 (1Y)
/motor_3/ENCA_N: C51.2, J23.5, U15.7 (1IN-)
/motor_3/ENCA_P: J23.6, R53.2, U15.1 (1IN+)
/motor_3/ENCA_S: U15.2 (1OUT), U17.1 (1A)
/motor_3/ENCB: U14.18 (PA7), U17.5 (2Y)
/motor_3/ENCB_N: C52.2, J23.7, U15.5 (2IN-)
/motor_3/ENCB_P: J23.8, R54.2, U15.6 (2IN+)
/motor_3/ENCB_S: U15.3 (2OUT), U17.3 (2A)
/motor_3/H1: U14.11 (PA0), U16.7 (1Y)
/motor_3/H1_A: J22.1, U16.1 (1A)
/motor_3/H2: U14.12 (PA1), U16.5 (2Y)
/motor_3/H2_A: J22.2, U16.3 (2A)
/motor_3/H3: U14.13 (PA2), U16.2 (3Y)
/motor_3/H3_A: J22.5, U16.6 (3A)
/motor_3/HSU: R55.1, U14.33 (HSU)
/motor_3/HSV: R57.1, U14.29 (HSV)
/motor_3/HSW: R59.1, U14.25 (HSW)
/motor_3/LSU: R56.1, U14.36 (LSU)
/motor_3/LSV: R58.1, U14.32 (LSV)
/motor_3/LSW: R60.1, U14.28 (LSW)
/motor_3/MOTOR_LED: Q21.1 (G), U14.19 (PB1)
/motor_3/PHASE_U: C55.2, J22.7, Q15.3 (S), Q16.2 (D), U14.34 (OUTU)
/motor_3/PHASE_V: C56.2, J22.8, Q17.3 (S), Q18.2 (D), U14.30 (OUTV)
/motor_3/PHASE_W: C57.2, J22.4, Q19.3 (S), Q20.2 (D), U14.26 (OUTW)
/motor_3/SENSE_N1: R63.2, R66.1, U14.22 (OP1N)
/motor_3/SENSE_O1: R66.2, U14.14 (PA3), U14.21 (OP1O), U14.24 (OC_COMP)
/motor_3/SENSE_P1: R62.2, R65.1, U14.23 (OP1P)
/motor_3/SWD_CLK: J24.2, U14.38 (PA14_SWD_CLK)
/motor_3/SWD_IO: J24.1, U14.37 (PA13_SWD_IO)
/motor_4/ENCA: U18.17 (PA6), U21.7 (1Y)
/motor_4/ENCA_N: C72.2, J26.5, U19.7 (1IN-)
/motor_4/ENCA_P: J26.6, R68.2, U19.1 (1IN+)
/motor_4/ENCA_S: U19.2 (1OUT), U21.1 (1A)
/motor_4/ENCB: U18.18 (PA7), U21.5 (2Y)
/motor_4/ENCB_N: C73.2, J26.7, U19.5 (2IN-)
/motor_4/ENCB_P: J26.8, R69.2, U19.6 (2IN+)
/motor_4/ENCB_S: U19.3 (2OUT), U21.3 (2A)
/motor_4/H1: U18.11 (PA0), U20.7 (1Y)
/motor_4/H1_A: J25.1, U20.1 (1A)
/motor_4/H2: U18.12 (PA1), U20.5 (2Y)
/motor_4/H2_A: J25.2, U20.3 (2A)
/motor_4/H3: U18.13 (PA2), U20.2 (3Y)
/motor_4/H3_A: J25.5, U20.6 (3A)
/motor_4/HSU: R70.1, U18.33 (HSU)
/motor_4/HSV: R72.1, U18.29 (HSV)
/motor_4/HSW: R74.1, U18.25 (HSW)
/motor_4/LSU: R71.1, U18.36 (LSU)
/motor_4/LSV: R73.1, U18.32 (LSV)
/motor_4/LSW: R75.1, U18.28 (LSW)
/motor_4/MOTOR_LED: Q28.1 (G), U18.19 (PB1)
/motor_4/PHASE_U: C76.2, J25.7, Q22.3 (S), Q23.2 (D), U18.34 (OUTU)
/motor_4/PHASE_V: C77.2, J25.8, Q24.3 (S), Q25.2 (D), U18.30 (OUTV)
/motor_4/PHASE_W: C78.2, J25.4, Q26.3 (S), Q27.2 (D), U18.26 (OUTW)
/motor_4/SENSE_N1: R78.2, R81.1, U18.22 (OP1N)
/motor_4/SENSE_O1: R81.2, U18.14 (PA3), U18.21 (OP1O), U18.24 (OC_COMP)
/motor_4/SENSE_P1: R77.2, R80.1, U18.23 (OP1P)
/motor_4/SWD_CLK: J27.2, U18.38 (PA14_SWD_CLK)
/motor_4/SWD_IO: J27.1, U18.37 (PA13_SWD_IO)
/~M2_RST: U10.7 (NRST); also elsewhere on the board
/~M3_RST: U14.7 (NRST); also elsewhere on the board
/~M4_RST: U18.7 (NRST); also elsewhere on the board
GND: C32.1, C33.2, C37.2, C38.2, C39.2, C40.2, C41.2, C42.2, C43.2, C44.2, C45.2, C46.2, C47.2, C48.2, C49.2, C50.2, C53.1, C54.2, C58.2, C59.2, C60.2, C61.2, C62.2, C63.2, C64.2, C65.2, C66.2, C67.2, C68.2, C69.2, C70.2, C71.2, C74.1, C75.2, C79.2, C80.2, C81.2, C82.2, C83.2, C84.2, C85.2, C86.2, C87.2, C88.2, C89.2, C90.2, C91.2, C92.2, J19.6, J20.3, J22.6, J23.3, J25.6, J26.3, Q14.2 (S), Q21.2 (S), Q28.2 (S), R37.2, R46.1, R48.1, R50.2, R52.2, R61.1, R63.1, R65.2, R67.2, R76.1, R78.1, R80.2, U10.1 (OP2P), U10.20 (TESTMODE), U10.44 (GND), U10.45 (OP3P), U10.49 (EPAD), U11.4 (GND), U12.4 (GND), U13.4 (GND), U14.1 (OP2P), U14.20 (TESTMODE), U14.44 (GND), U14.45 (OP3P), U14.49 (EPAD), U15.4 (GND), U16.4 (GND), U17.4 (GND), U18.1 (OP2P), U18.20 (TESTMODE), U18.44 (GND), U18.45 (OP3P), U18.49 (EPAD), U19.4 (GND), U20.4 (GND), U21.4 (GND); also elsewhere on the board
unnamed: C30.1, R38.1
unnamed: C31.1, R39.1
unnamed: C51.1, R53.1
unnamed: C52.1, R54.1
unnamed: C72.1, R68.1
unnamed: C73.1, R69.1
unnamed: D5.2 (A), R49.1
unnamed: D5.1 (K), Q14.3 (D)
unnamed: D6.2 (A), R64.1
unnamed: D6.1 (K), Q21.3 (D)
unnamed: D7.2 (A), R79.1
unnamed: D7.1 (K), Q28.3 (D)
unnamed: Q8.1 (G), R40.2
unnamed: Q9.1 (G), R41.2
unnamed: Q10.1 (G), R42.2
unnamed: Q11.1 (G), R43.2
unnamed: Q9.3 (S), Q11.3 (S), Q13.3 (S), R46.2, R47.1
unnamed: Q12.1 (G), R44.2
unnamed: Q13.1 (G), R45.2
unnamed: Q15.1 (G), R55.2
unnamed: Q16.1 (G), R56.2
unnamed: Q16.3 (S), Q18.3 (S), Q20.3 (S), R61.2, R62.1
unnamed: Q17.1 (G), R57.2
unnamed: Q18.1 (G), R58.2
unnamed: Q19.1 (G), R59.2
unnamed: Q20.1 (G), R60.2
unnamed: Q22.1 (G), R70.2
unnamed: Q23.1 (G), R71.2
unnamed: Q23.3 (S), Q25.3 (S), Q27.3 (S), R76.2, R77.1
unnamed: Q24.1 (G), R72.2
unnamed: Q25.1 (G), R73.2
unnamed: Q26.1 (G), R74.2
unnamed: Q27.1 (G), R75.2
unnamed: U10.2 (OP2N), U10.3 (OP2O)
unnamed: U10.46 (OP3N), U10.47 (OP3O)
unnamed: C34.1, U10.35 (VBOOTU)
unnamed: C35.1, U10.31 (VBOOTV)
unnamed: C36.1, U10.27 (VBOOTW)
unnamed: C33.1, U10.6 (VREG12)
unnamed: U14.2 (OP2N), U14.3 (OP2O)
unnamed: U14.46 (OP3N), U14.47 (OP3O)
unnamed: C55.1, U14.35 (VBOOTU)
unnamed: C56.1, U14.31 (VBOOTV)
unnamed: C57.1, U14.27 (VBOOTW)
unnamed: C54.1, U14.6 (VREG12)
unnamed: U18.2 (OP2N), U18.3 (OP2O)
unnamed: U18.46 (OP3N), U18.47 (OP3O)
unnamed: C76.1, U18.35 (VBOOTU)
unnamed: C77.1, U18.31 (VBOOTV)
unnamed: C78.1, U18.27 (VBOOTW)
unnamed: C75.1, U18.6 (VREG12)
VDC: C39.1, C41.1, C42.1, C43.1, C44.1, C45.1, C46.1, C47.1, C48.1, C49.1, C50.1, C60.1, C62.1, C63.1, C64.1, C65.1, C66.1, C67.1, C68.1, C69.1, C70.1, C71.1, C81.1, C83.1, C84.1, C85.1, C86.1, C87.1, C88.1, C89.1, C90.1, C91.1, C92.1, Q8.2 (D), Q10.2 (D), Q12.2 (D), Q15.2 (D), Q17.2 (D), Q19.2 (D), Q22.2 (D), Q24.2 (D), Q26.2 (D), U10.8 (VM), U14.8 (VM), U18.8 (VM); also elsewhere on the board

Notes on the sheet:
large decoupling
Shunt should be rated for at least 1/2 W = 500mW
Dual Differential Line Receiver
Config for unused op amps
Encoder Connectors
UART_TX moved from PA14 to PB6
Line Receiver RC between Complements
Motor and Hall Sensor Connectors
Schmitt triggers.
MOTOR status LED
TODO: Fix encoder connector footprint
3.3v is supplied by monolithic regulator
Two decoupling for each phase line
SWD Header
4 VDC general decoupling
Low Side BLDC Current Sensing
Set OC_COMP to 255 mV (PF6 = 1, PF7 = 0)
Intention is to use Segger J-Link for SWD. See chapter 15 of linked document. Embedded MCU (STM32F031C6) has internal pull-up for SWD_IO and pull-down for SWD_CLK (footnote 5 in STM32F031C6 datasheet) which are enabled by default on reset.

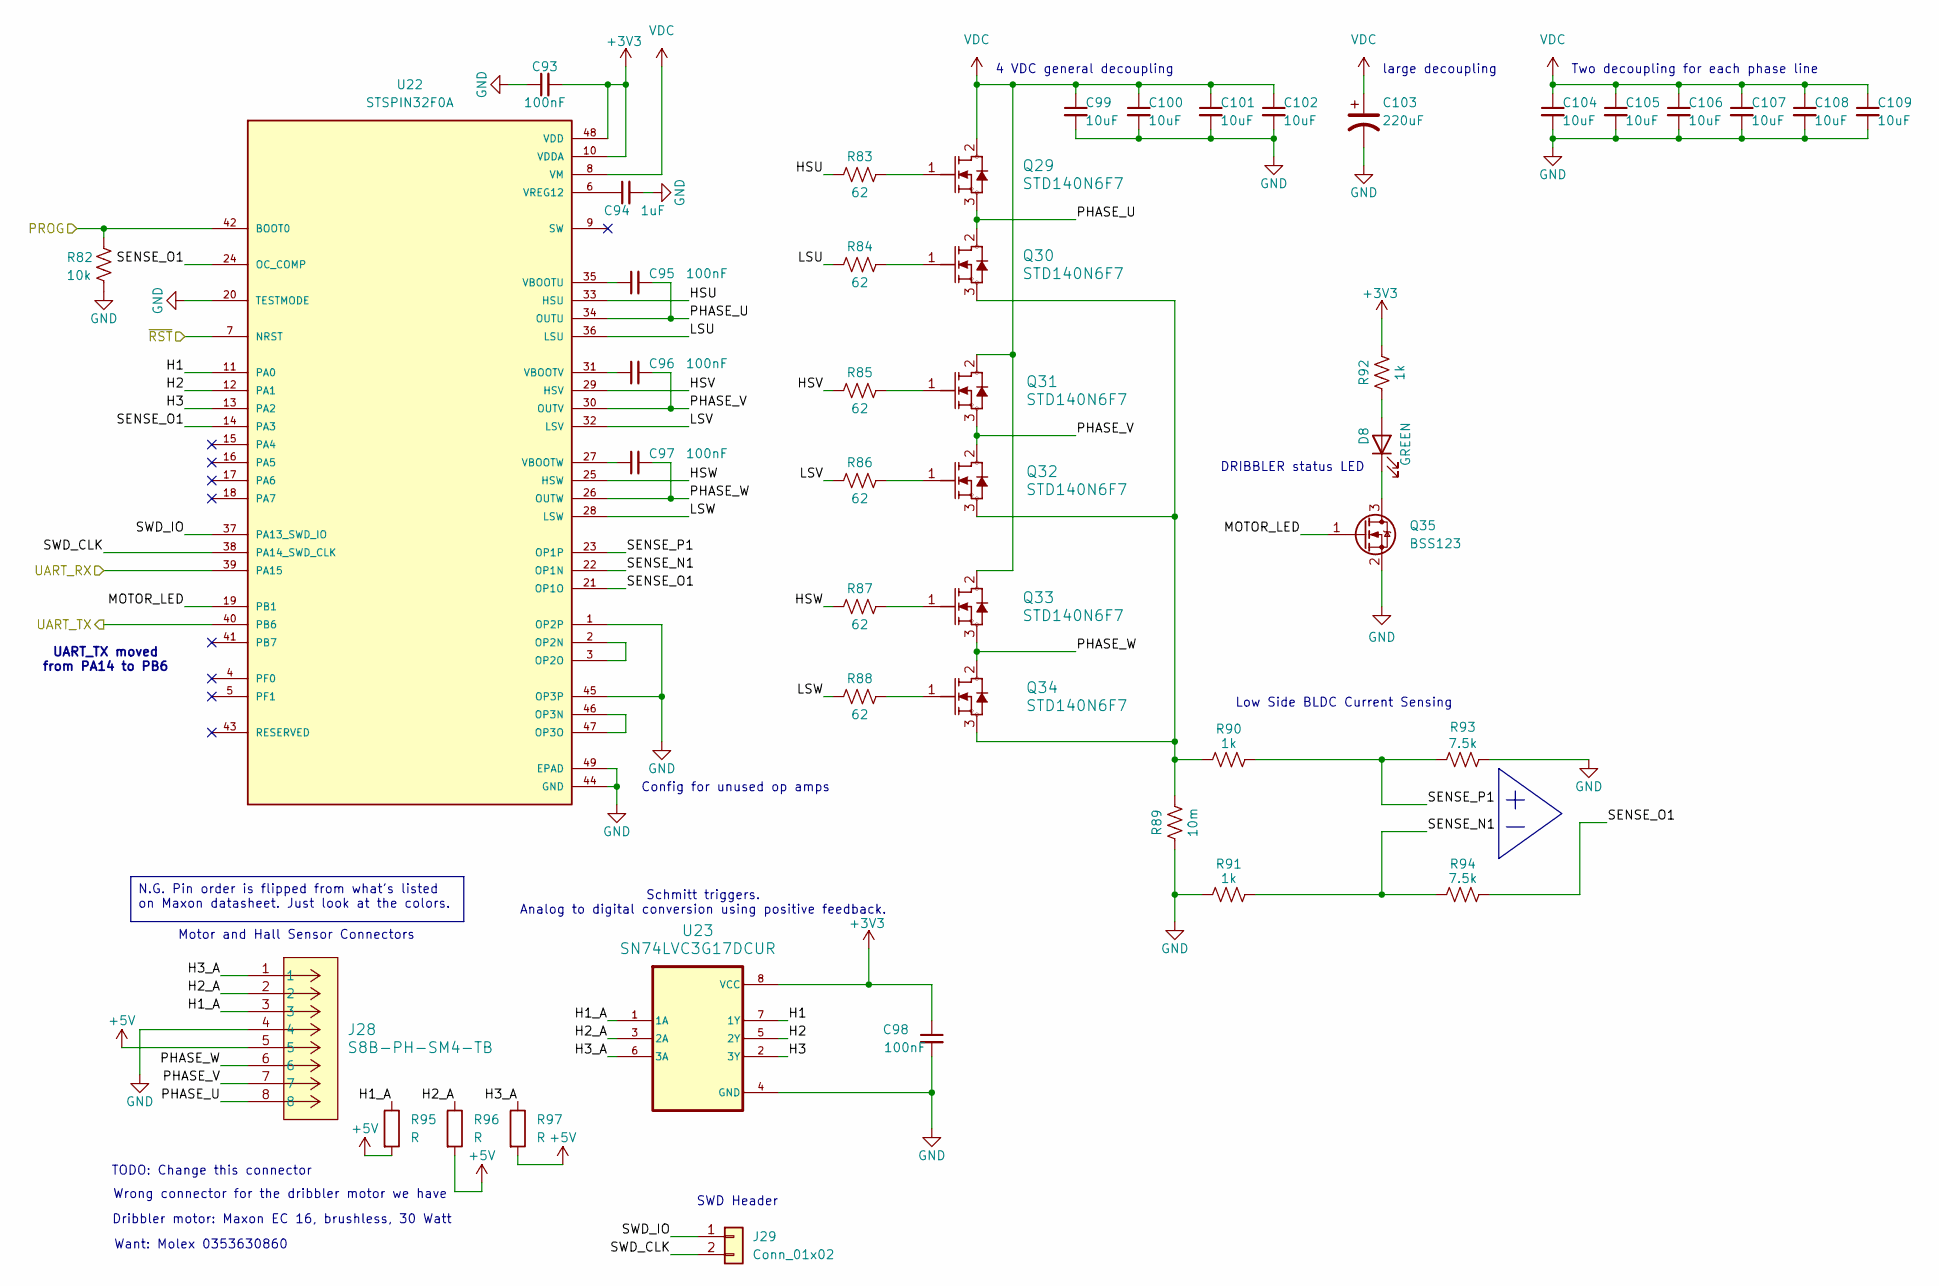
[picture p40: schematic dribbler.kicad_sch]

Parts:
C93, C95, C96, C97, C98: 100nF; C_0603_1608Metric
C94: 1uF; C_0603_1608Metric
C99, C100, C101, C102, C104, C105, C106, C107, C108, C109: 10uF; C_1206_3216Metric
C103: 220uF; CP_Elec_6.3x7.7
D8: GREEN; D_0603_1608Metric
J28: S8B-PH-SM4-TB; CONN_S8B-PH-SM4-TB_JST; Manufacturer P/N S8B-PH-SM4-TB
J29: Conn_01x02; PinHeader_1x02_P2.54mm_Vertical
Q29, Q30, Q31, Q32, Q33, Q34: STD140N6F7; DPAKTO-252_A2_STM; Manufacturer P/N STD140N6F7
Q35: BSS123; SOT-23
R82: 10k; R_0603_1608Metric
R83, R84, R85, R86, R87, R88: 62; R_0603_1608Metric
R89: 10m; R_1206_3216Metric
R90, R91, R92: 1k; R_0603_1608Metric
R93, R94: 7.5k; R_0603_1608Metric
R95, R96, R97: R; R_0603_1608Metric
U22: STSPIN32F0A; IC_STSPIN32F0A; Manufacturer P/N STSPIN32F0A
U23: SN74LVC3G17DCUR; SOP50P310X90-8N; Manufacturer P/N SN74LVC3G17DCTR

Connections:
+3V3: C93.2, C98.1, R92.2, U22.10 (VDDA), U22.48 (VDD), U23.8 (VCC); also elsewhere on the board
+5V: J28.5, R95.2, R96.2, R97.2; also elsewhere on the board
/DRIB_PROG: R82.1, U22.42 (BOOT0); also elsewhere on the board
/DRIB_UART_RX: U22.39 (PA15); also elsewhere on the board
/DRIB_UART_TX: U22.40 (PB6); also elsewhere on the board
/dribbler/H1: U22.11 (PA0), U23.7 (1Y)
/dribbler/H1_A: J28.3, R95.1, U23.1 (1A)
/dribbler/H2: U22.12 (PA1), U23.5 (2Y)
/dribbler/H2_A: J28.2, R96.1, U23.3 (2A)
/dribbler/H3: U22.13 (PA2), U23.2 (3Y)
/dribbler/H3_A: J28.1, R97.1, U23.6 (3A)
/dribbler/HSU: R83.1, U22.33 (HSU)
/dribbler/HSV: R85.1, U22.29 (HSV)
/dribbler/HSW: R87.1, U22.25 (HSW)
/dribbler/LSU: R84.1, U22.36 (LSU)
/dribbler/LSV: R86.1, U22.32 (LSV)
/dribbler/LSW: R88.1, U22.28 (LSW)
/dribbler/MOTOR_LED: Q35.1 (G), U22.19 (PB1)
/dribbler/PHASE_U: C95.2, J28.8, Q29.3 (S), Q30.2 (D), U22.34 (OUTU)
/dribbler/PHASE_V: C96.2, J28.7, Q31.3 (S), Q32.2 (D), U22.30 (OUTV)
/dribbler/PHASE_W: C97.2, J28.6, Q33.3 (S), Q34.2 (D), U22.26 (OUTW)
/dribbler/SENSE_N1: R91.2, R94.1, U22.22 (OP1N)
/dribbler/SENSE_O1: R94.2, U22.14 (PA3), U22.21 (OP1O), U22.24 (OC_COMP)
/dribbler/SENSE_P1: R90.2, R93.1, U22.23 (OP1P)
/dribbler/SWD_CLK: J29.2, U22.38 (PA14_SWD_CLK)
/dribbler/SWD_IO: J29.1, U22.37 (PA13_SWD_IO)
/~DRIB_RST: U22.7 (NRST); also elsewhere on the board
GND: C93.1, C94.2, C98.2, C99.2, C100.2, C101.2, C102.2, C103.2, C104.2, C105.2, C106.2, C107.2, C108.2, C109.2, J28.4, Q35.2 (S), R82.2, R89.1, R91.1, R93.2, U22.1 (OP2P), U22.20 (TESTMODE), U22.44 (GND), U22.45 (OP3P), U22.49 (EPAD), U23.4 (GND); also elsewhere on the board
unnamed: D8.2 (A), R92.1
unnamed: D8.1 (K), Q35.3 (D)
unnamed: Q29.1 (G), R83.2
unnamed: Q30.1 (G), R84.2
unnamed: Q30.3 (S), Q32.3 (S), Q34.3 (S), R89.2, R90.1
unnamed: Q31.1 (G), R85.2
unnamed: Q32.1 (G), R86.2
unnamed: Q33.1 (G), R87.2
unnamed: Q34.1 (G), R88.2
unnamed: U22.2 (OP2N), U22.3 (OP2O)
unnamed: U22.46 (OP3N), U22.47 (OP3O)
unnamed: C95.1, U22.35 (VBOOTU)
unnamed: C96.1, U22.31 (VBOOTV)
unnamed: C97.1, U22.27 (VBOOTW)
unnamed: C94.1, U22.6 (VREG12)
VDC: C99.1, C100.1, C101.1, C102.1, C103.1, C104.1, C105.1, C106.1, C107.1, C108.1, C109.1, Q29.2 (D), Q31.2 (D), Q33.2 (D), U22.8 (VM); also elsewhere on the board

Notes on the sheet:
Dribbler motor: Maxon EC 16, brushless, 30 Watt
Low Side BLDC Current Sensing
TODO: Change this connector
Config for unused op amps
Wrong connector for the dribbler motor we have
SWD Header
DRIBBLER status LED
Want: Molex 0353630860
Two decoupling for each phase line
Motor and Hall Sensor Connectors
4 VDC general decoupling
large decoupling
Schmitt triggers. Analog to digital conversion using positive feedback.
UART_TX moved from PA14 to PB6
N.G. Pin order is flipped from what's listed on Maxon datasheet. Just look at the colors.

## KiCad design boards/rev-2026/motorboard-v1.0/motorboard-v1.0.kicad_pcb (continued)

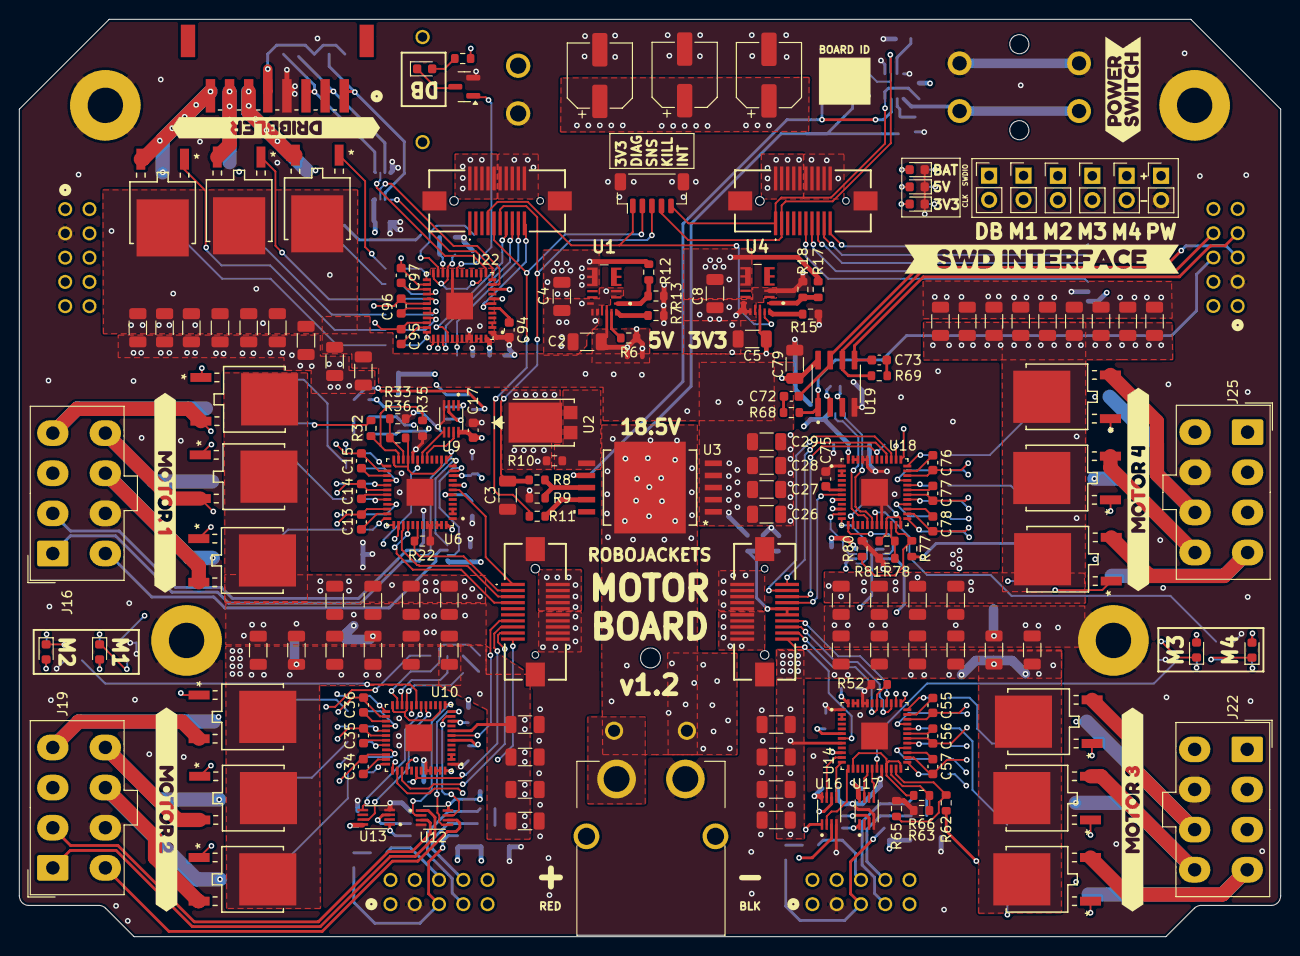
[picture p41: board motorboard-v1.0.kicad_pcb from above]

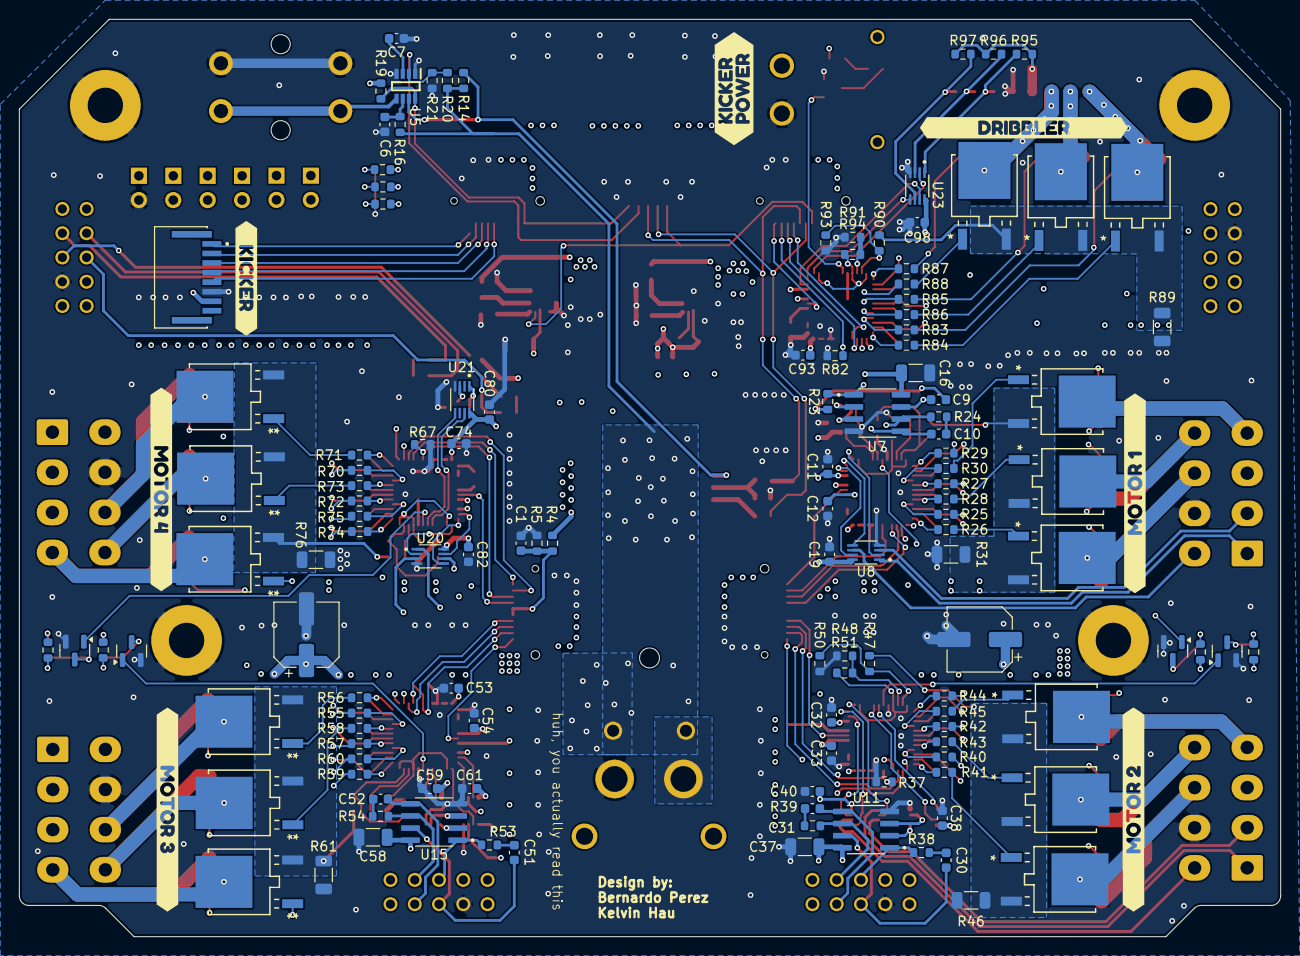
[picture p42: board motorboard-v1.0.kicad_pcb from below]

Board: 4 copper layers, 132.0 x 96.0 mm, 315 parts (135 on the bottom side), 272 nets.

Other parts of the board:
kibuzzard-679DAD2E: G***; kibuzzard-679DAD2E
kibuzzard-679DAD96, kibuzzard-679DAD96#2: G***; kibuzzard-679DAD96
kibuzzard-679DB05F, kibuzzard-679DB05F#2: G***; kibuzzard-679DB05F
kibuzzard-679DB7F8: G***; kibuzzard-679DB7F8
kibuzzard-679DB9B8: G***; kibuzzard-679DB9B8
kibuzzard-679DB034, kibuzzard-679DB034#2: G***; kibuzzard-679DB034
kibuzzard-679DB049, kibuzzard-679DB049#2: G***; kibuzzard-679DB049
kibuzzard-679DB095, kibuzzard-679DB095#2: G***; kibuzzard-679DB095
kibuzzard-679DBA21: G***; kibuzzard-679DBA21

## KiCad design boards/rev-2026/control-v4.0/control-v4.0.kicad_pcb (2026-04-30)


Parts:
Brd1: SSD1306; Adafruit_SSD1306_No_Mounting_Holes
C1: 10uF; C_0603_1608Metric
D1, D2: LED; D_0603_1608Metric
J1, J2, J3, J4: 53625-0274; 536250274; Manufacturer P/N 0536250274
R1, R2: 4.7K; R_0603_1608Metric
R3, R4: 1K; R_0603_1608Metric
SW1: SW_DIP_x04; 418117270904
SW3: 3-1825910-1; TE_3-1825910-1; PARTREV C10
U1: NRF24L01_Breakout; nRF24L01_Breakout
U2: IMU Header; HeaderIMUFooter
U3: Teensy4.1; Teensy41

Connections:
+3.3V: C1.1, D2.2 (A), J1.2, J1.4, J1.6, J1.8, J1.10, J4.2, J4.4, J4.6, J4.8, J4.10, R1.2, R2.2, U1.2 (VCC), U2.4 (~CS), U2.8 (3.3V)
+5V: Brd1.2 (VCC), D1.2 (A), J2.2, J2.4, J2.6, J2.8, J2.10, J3.2, J3.4, J3.6, J3.8, J3.10, U3.48 (VIN)
/3V3_EN: J1.7, U3.45 (23_A9_CRX1_MCLK1)
/DIAG_EN: J1.9, U3.39 (17_A3_TX4_SDA1)
/DRIB_PROG: J1.17, U3.44 (22_A8_CTX1)
/DRIB_UART_RX: J1.15, U3.42 (20_A6_TX5_LRCLK1)
/DRIB_UART_TX: J1.13, U3.43 (21_A7_RX5_BCLK1)
/HEX_0: SW1.1, U3.27 (35_TX8)
/HEX_1: SW1.2, U3.26 (34_RX8)
/HEX_2: SW1.3, U3.25 (33_MCLK2)
/HEX_3: SW1.4, U3.24 (32_OUT1B)
/M1_PROG: J2.3, U3.4 (2_OUT2)
/M1_UART_RX: J2.5, U3.3 (1_TX1_CTX2_MISO1)
/M1_UART_TX: J2.7, U3.2 (0_RX1_CRX2_CS1)
/M2_PROG: J2.15, U3.8 (6_OUT1D)
/M2_UART_RX: J2.17, U3.10 (8_TX2_IN1)
/M2_UART_TX: J2.19, U3.9 (7_RX2_OUT1A)
/M3_PROG: J3.3, U3.23 (31_CTX3)
/M3_UART_RX: J3.5, U3.16 (24_A10_TX6_SCL2)
/M3_UART_TX: J3.7, U3.17 (25_A11_RX6_SDA2)
/M4_PROG: J3.15, U3.22 (30_CRX3)
/M4_UART_RX: J3.17, U3.21 (29_TX7)
/M4_UART_TX: J3.19, U3.20 (28_RX7)
/MISO_KICK: J4.19, U3.31 (39_MISO1_OUT1A)
/MOSI_KICK: J4.17, U3.18 (26_A12_MOSI1)
/M_RESET: J1.19, J2.1, J2.13, J3.1, J3.13, SW3.1, SW3.2, U3.7 (5_IN2); also elsewhere on the board
/RADIO_CE: U1.3 (CE), U3.33 (41_A17)
/RADIO_INT: U1.8 (IRQ), U3.11 (9_OUT1C)
/RADIO_MISO: U1.7 (MISO), U3.14 (12_MISO_MQSL)
/RADIO_MOSI: U1.6 (MOSI), U3.13 (11_MOSI_CTX1)
/RADIO_SCK: U1.5 (SCK), U3.35 (13_SCK_LED)
/RADIO_~CSN: U1.4 (~CSN), U3.12 (10_CS_MQSR)
/SCK_KICK: J4.15, U3.19 (27_A13_SCK1)
/SHARE_SCL: Brd1.3 (SCL), R1.1, U2.3 (SCK), U3.41 (19_A5_SCL)
/SHARE_SDA: Brd1.4 (SDA), R2.1, U2.1 (MOSI), U3.40 (18_A4_SDA)
/SNS: J1.11, U3.38 (16_A2_RX4_SCL1)
/VBAT_READ: J3.9, J3.11, U3.37 (15_A1_RX3_SPDIF_IN)
/~CS_KICK: J4.13, U3.30 (38_CS1_IN1)
/~INT: J4.1, U3.32 (40_A16)
/~KILL: J4.3, U3.28 (36_CS)
/~RST_KICK: J4.11, U3.29 (37_CS)
GND: Brd1.1 (GND), C1.2, J1.12, J1.14, J1.16, J1.18, J1.20, J1.MP1, J1.MP2, J2.12, J2.14, J2.16, J2.18, J2.20, J2.MP1, J2.MP2, J3.12, J3.14, J3.16, J3.18, J3.20, J3.MP1, J3.MP2, J4.12, J4.14, J4.16, J4.18, J4.20, J4.MP1, J4.MP2, R3.1, R4.1, SW1.5, SW1.6, SW1.7, SW1.8, SW3.3, SW3.4, U1.1 (GND), U2.2 (MISO), U2.5 (GND), U3.1 (GND), U3.34 (GND), U3.47 (GND); also elsewhere on the board
unnamed: D1.1 (K), R3.2
unnamed: D2.1 (K), R4.2

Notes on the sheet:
Debug Power
We don't use IMU Interrupt Addr is just pulled low bc we don't need extra i2c addr
Peripherals
Microcontroller
Board ID
Reset Switch
Connectors



Board: 4 copper layers, 64.0 x 66.0 mm, 17 parts (9 on the bottom side), 44 nets.

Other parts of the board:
SW2: SW_Push; TE_3-1825910-1

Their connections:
/M_RESET: SW2.1; also elsewhere on the board
GND: SW2.2; also elsewhere on the board

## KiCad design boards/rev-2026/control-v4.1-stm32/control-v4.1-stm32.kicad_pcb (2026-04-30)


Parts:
C1, C2: 2.2uF; C_0603_1608Metric
C3, C4, C5, C6, C7, C8, C13, C19: 100nF; C_0603_1608Metric
C9: 4.2uF; C_0603_1608Metric
C10: 4.7uF; C_0603_1608Metric
C12, C14: 1uF; C_0603_1608Metric
C15, C16: 10pF; C_0603_1608Metric
C17, C18: 12pF; C_0603_1608Metric; not fitted
C20: 22pF; C_0603_1608Metric
C21, C22: 10uF; C_0603_1608Metric
D1: B5819WS-TP; SOD2512X115N; Mouser Part Number 833-B5819WS-TP
D2, D3, D8, D9, D10: PJSD05TS; SOD-523_0P9X1P3_ONS
D4, D5, D6, D7: TPD1E04U04DPYR; DPY2_TEX
D11, D12, D13, D14, D15, D16: LED; D_0603_1608Metric
FB1: 1K, 100Mhz; BEADC1608X95N; not fitted
J1, J3, J4, J5: 53625-0274; 536250274; Manufacturer P/N 0536250274
J2: Conn_01x04_Pin; PinHeader_1x04_P2.54mm_Vertical
J6: USB_C_Receptacle_USB2.0_16P; USB_C_Receptacle_GCT_USB4110
J7: Conn_01x04_Pin; Adafruit_SSD1306_No_Mounting_Holes
L1: 2.2uH; L_0603_1608Metric
R1, R2: 5.1k; R_0603_1608Metric
R3, R4, R5, R6, R11: 10k; R_0603_1608Metric
R7, R8, R9, R10: 330; R_0603_1608Metric
R12: 680k; R_0603_1608Metric
R13: 150k; R_0603_1608Metric
R14, R23: 210k; R_0603_1608Metric
R15, R18, R24, R25: 100k; R_0603_1608Metric
R19, R20, R21, R22, R26, R27: 1k; R_0603_1608Metric
SW1, SW2, SW4: SW_Push; SW_PUSH_6mm
SW3: SW_DIP_SPSTx04_Slide_9.78x12.34mm_W7.62mm_P2.54mm
U1: TLV62569DBV; SOT-23-5
U2, U6: TPS2117DRLR; SOTFL50P160X60-8N; PARTREV A
U3: STM32H723VGTx; LQFP-100_14x14mm_P0.5mm
U4: HeaderIMUFooter
U5: NRF24L01_Breakout; nRF24L01_Breakout
Y1: 25 MHz 10 pF; XTAL_ABM8-25.000MHz-10-B1U-T
Y2: 32.768K 7pF; XTAL_ABS07-32.768KHZ-T; not fitted

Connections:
3V3: D13.2 (A), J1.2, J1.4, J1.6, J1.8, J1.10, J3.2, J3.4, J3.6, J3.8, J3.10, U2.6 (VIN2)
3V3_USB: C20.1, C21.1, D9.1 (A1), D12.2 (A), J2.4, L1.2, R12.1, R14.1, R18.2, R25.2, U2.3 (VIN1), U2.5 (MODE)
+5V: D16.2 (A), J4.2, J4.4, J4.6, J4.8, J4.10, J5.2, J5.4, J5.6, J5.8, J5.10, U6.6 (VIN2)
+5V_OUT: D11.2 (A), J7.2, U6.2 (VOUT), U6.7 (VOUT__1)
/3V3_EN: J1.7, U3.16 (PC1)
/BOOT0: D2.2 (A2), R11.2, SW2.2, U3.94 (BOOT0)
/DIAG_EN: J1.9, U3.17 (PC2_C)
/DRIB_PROG: J1.17, U3.15 (PC0)
/DRIB_UART_RX: J1.15, U3.23 (PA1)
/DRIB_UART_TX: J1.13, U3.22 (PA0)
/I2C1_SCL: U3.95 (PB8), U4.3 (SCK)
/I2C1_SDA: U3.96 (PB9), U4.1 (MOSI)
/I2C2_SCL: J7.3, U3.46 (PB10)
/I2C2_SDA: J7.4, U3.47 (PB11)
/M1_PROG: J4.3, U3.88 (PD7)
/M1_UART_RX: J4.7, U3.90 (PB4(NJTRST))
/M1_UART_TX: J4.5, U3.89 (PB3(JTDO)
/M2_PROG: J4.15, U3.91 (PB5)
/M2_UART_RX: J4.19, U3.93 (PB7)
/M2_UART_TX: J4.17, U3.92 (PB6)
/M3_PROG: J5.3, U3.54 (PB15)
/M3_UART_RX: J5.7, U3.56 (PD9)
/M3_UART_TX: J5.5, U3.55 (PD8)
/M4_PROG: J5.15, U3.62 (PD15)
/M4_UART_RX: J5.19, U3.63 (PC6)
/M4_UART_TX: J5.17, U3.64 (PC7)
/MISO_KICK: J3.19, U3.31 (PA7)
/MOSI_KICK: J3.17, U3.30 (PA6)
/M_RESET: D10.2 (A2), J1.19, J4.1, J4.13, J5.1, J5.13, SW4.2, U3.77 (PA15(JTDI))
/NRST: C19.1, D3.2 (A2), SW1.2, U3.14 (NRST)
/PA13: D5.2 (A2), J2.2, U3.72 (PA13(JTMS)
/PA14: D4.2 (A2), J2.1, U3.76 (PA14(JTCK)
/RADIO_CE: U3.39 (PE9), U5.3 (CE)
/RADIO_INT: U3.40 (PE10), U5.8 (IRQ)
/RADIO_MISO: U3.43 (PE13), U5.7 (MISO)
/RADIO_MOSI: U3.44 (PE14), U5.6 (MOSI)
/RADIO_SCK: U3.42 (PE12), U5.5 (SCK)
/RADIO_~CSN: U3.41 (PE11), U5.4 (~CSN)
/S1: R7.1, U3.4 (PE5)
/S2: R8.1, U3.3 (PE4)
/S3: R9.1, U3.2 (PE3)
/S4: R10.1, U3.1 (PE2)
/SCK_KICK: J3.15, U3.29 (PA5)
/SNS: J1.11, U3.18 (PC3_C)
/SPI1_NSS: U3.28 (PA4)
/ST1: R18.1, U2.8 (ST), U3.66 (PC9)
/ST2: R25.1, U3.67 (PA8), U6.8 (ST)
/UART5_RX: U3.51 (PB12)
/UART5_TX: U3.52 (PB13)
/USART2_RX_BOOT: U3.25 (PA3)
/USART2_TX_BOOT: U3.24 (PA2)
/USB_DM: D6.1 (A1), J6.A7 (D-), J6.B7 (D-), U3.70 (PA11)
/USB_DP: D7.1 (A1), J6.A6 (D+), J6.B6 (D+), U3.71 (PA12)
/USB_ID: U3.69 (PA10)
/VBAT_READ: J5.9, J5.11, U3.34 (PB0)
/VREF: C3.2, C12.2, C13.2, C14.2, FB1.2, U3.20 (VREF+), U3.21 (VDDA)
/~CS_KICK: J3.13, U3.32 (PC4)
/~INT: J3.1, U3.35 (PB1)
/~KILL: J3.3, U3.36 (PB2)
/~RST_KICK: J3.11, U3.33 (PC5)
GNDREF: C1.2, C2.2, C3.1, C4.2, C5.2, C6.2, C7.2, C8.2, C9.2, C10.2, C12.1, C13.1, C14.1, C15.1, C16.1, C17.2, C18.2, C19.2, C21.2, C22.2, D2.1 (A1), D3.1 (A1), D4.1 (A1), D5.1 (A1), D6.2 (A2), D7.2 (A2), D8.2 (A2), D9.2 (A2), D10.1 (A1), J1.12, J1.14, J1.16, J1.18, J1.20, J1.MP1, J1.MP2, J2.3, J3.12, J3.14, J3.16, J3.18, J3.20, J3.MP1, J3.MP2, J4.12, J4.14, J4.16, J4.18, J4.20, J4.MP1, J4.MP2, J5.12, J5.14, J5.16, J5.18, J5.20, J5.MP1, J5.MP2, J6.A1 (GND), J6.A12 (GND), J6.B1 (GND), J6.B12 (GND), J7.1, R1.1, R2.1, R3.1, R4.1, R5.1, R6.1, R11.1, R13.2, R15.2, R19.1, R20.1, R21.1, R22.1, R24.2, R26.1, R27.1, SW1.1, SW4.1, U1.2 (GND), U2.1 (GND), U3.10 (VSS), U3.19 (VSSA), U3.26 (VSS), U3.49 (VSS), U3.74 (VSS), U3.99 (VSS), U4.2 (MISO), U4.5 (GND), U5.1 (GND), U6.1 (GND), Y1.2, Y1.4
unnamed: C1.1, U3.48 (VCAP)
unnamed: C2.1, U3.73 (VCAP)
unnamed: C10.1, D1.2 (K), D8.1 (A1), U1.1 (EN), U1.4 (VIN)
unnamed: D11.1 (K), R19.2
unnamed: D12.1 (K), R20.2
unnamed: D13.1 (K), R21.2
unnamed: D14.1 (K), R22.2
unnamed: D15.1 (K), R26.2
unnamed: D16.1 (K), R27.2
unnamed: J6.A5 (CC1), R1.2
unnamed: J6.B5 (CC2), R2.2
unnamed: R3.2, R7.2, SW3.8
unnamed: R4.2, R8.2, SW3.7
unnamed: R5.2, R9.2, SW3.6
unnamed: R6.2, R10.2, SW3.5
unnamed: C20.2, R12.2, R13.1, U1.5 (FB)
unnamed: L1.1, U1.3 (SW)
unnamed: R14.2, R15.1, U2.4 (PR1)
unnamed: C17.1, U3.8 (PC14), Y2.1
unnamed: C18.1, U3.9 (PC15), Y2.2
unnamed: C16.2, U3.12 (PH0), Y1.3
unnamed: C15.2, U3.13 (PH1), Y1.1
unnamed: R23.2, R24.1, U6.4 (PR1)
VBUS: D1.1 (A), D15.2 (A), J6.A4 (VBUS), J6.A9 (VBUS), J6.B4 (VBUS), J6.B9 (VBUS), R23.1, U6.3 (VIN1), U6.5 (MODE)
VDDMCU: C4.1, C5.1, C6.1, C7.1, C8.1, C9.1, C22.1, D14.2 (A), FB1.1, SW2.1, SW3.1, SW3.2, SW3.3, SW3.4, U2.2 (VOUT), U2.7 (VOUT__1), U3.11 (VDD), U3.27 (VDD), U3.50 (VDD), U3.75 (VDD), U3.100 (VDD), U4.4 (~CS), U4.8 (3.3V), U5.2 (VCC)

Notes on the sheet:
Power MUX 3v3
Check if it is supposed to be conencted
NEVER CONNECT DEBUGGER AND USB SIMUL.
M_RESET Settings
ANALOG
Add diode here
Power MUX 5v
figure calculations
Radio Goes BRR
Change to 180k
Debug Pins.
USB Stuff
Decoupling Capacitors
LED
DIP Switches
1 pF trace
BOOT Settings
IMU
MotorBoard Connectors
Check if this pin works
OLED
Reset Circuit



Board: 4 copper layers, 72.7 x 57.8 mm, 83 parts (63 on the bottom side), 80 nets.

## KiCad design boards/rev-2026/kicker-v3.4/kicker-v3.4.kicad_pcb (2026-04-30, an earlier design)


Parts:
C27, C28, C31, C32, C33, C34, C35, C36, C37: 100n; C_0402_1005Metric
C29, C30: 1u; C_0402_1005Metric
C38: 100n; C_0603_1608Metric
C39, C40: 15p; C_0603_1608Metric
D12, D13, D14: LED; LED_0603_1608Metric
J8: FF Cable; AMPHENOL_HFW8R-1STE1H1LF; Manufacturer P/N HFW8R-1STE1H1LF
R27: 10k; R_0603_1608Metric
R28: 1k; R_0603_1608Metric
R29, R30: 27.4; R_0402_1005Metric
R31, R32, R33: 1.6k; R_0603_1608Metric
R35, R36: 100k; R_0603_1608Metric
R37: 40k; R_0603_1608Metric
R38: 1.96k; R_0603_1608Metric
R39: 10k; R_0603_1608Metric; not fitted
R40: 1k; R_0402_1005Metric
S1, S2: EVQ-P7A01P; SW_EVQ-P7A01P; Manufacturer P/N EVQ-P7A01P
TP1: SWD_CLK; TestPoint_THTPad_1.5x1.5mm_Drill0.7mm
TP2: SWD_IO; TestPoint_THTPad_1.5x1.5mm_Drill0.7mm
TP3: SWD_GND; TestPoint_THTPad_1.5x1.5mm_Drill0.7mm
TP4: ~{SPI_CS}; TestPoint_Pad_D1.0mm
TP5: SPI_SCK; TestPoint_Pad_D1.0mm
TP6: SPI_MOSI; TestPoint_Pad_D1.0mm
TP7: SPI_MISO; TestPoint_Pad_D1.0mm
TP8: ~{RESET}; TestPoint_Pad_D1.0mm
TP9: HV_SENSE; TestPoint_Pad_D1.0mm
TP32, TP33: GND; TestPoint_Pad_D1.0mm
U8: RP2040; QFN-56-1EP_7x7mm_P0.4mm_EP3.2x3.2mm; Manufacturer P/N RP2040
U9: W25Q128JVS; SOIC-8_5.3x5.3mm_P1.27mm; Manufacturer P/N W25Q128JVS
Y1: ABM8-272-T3; Crystal_SMD_Abracon_ABM8AIG-4Pin_3.2x2.5mm; Manufacturer P/N ABM8-272-T3

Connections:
+3.3V: C30.1, C31.1, C32.1, C33.1, C34.1, C35.1, C36.1, C37.1, C38.1, R27.1, R39.1, U8.1 (IOVDD), U8.10 (IOVDD), U8.22 (IOVDD), U8.33 (IOVDD), U8.42 (IOVDD), U8.43 (ADC_AVDD), U8.44 (VREG_IN), U8.48 (USB_VDD), U8.49 (IOVDD), U9.8 (VCC); also elsewhere on the board
/Breakbeam/BB_SENSE: U8.40 (GPIO28_ADC2); also elsewhere on the board
/Breakbeam/BB_TRIGGER: U8.28 (GPIO17); also elsewhere on the board
/Capacitor Bank/HV: R35.2; also elsewhere on the board
/Debug Buttons/CHARGE_BTN: U8.2 (GPIO0); also elsewhere on the board
/Debug Buttons/CHIP_BTN: U8.3 (GPIO1); also elsewhere on the board
/Debug Buttons/KICK_BTN: U8.4 (GPIO2); also elsewhere on the board
/HV Discharge/CHIP_IN: U8.30 (GPIO19); also elsewhere on the board
/HV Discharge/DIS: U8.29 (GPIO18); also elsewhere on the board
/HV Discharge/KICK_IN: U8.31 (GPIO20); also elsewhere on the board
/HV Flyback/SYNC: U8.36 (GPIO24); also elsewhere on the board
/HV Flyback/~SHUTDOWN: U8.35 (GPIO23); also elsewhere on the board
/Indicator LEDs/BB_ACTIVE: U8.27 (GPIO16); also elsewhere on the board
/Indicator LEDs/HV0: U8.5 (GPIO3); also elsewhere on the board
/Indicator LEDs/HV1: U8.6 (GPIO4); also elsewhere on the board
/Indicator LEDs/HV2: U8.7 (GPIO5); also elsewhere on the board
/Indicator LEDs/HV3: U8.8 (GPIO6); also elsewhere on the board
/Indicator LEDs/HV4: U8.9 (GPIO7); also elsewhere on the board
/MCU/HV_SENSE: R37.1, R38.2, TP9.1, U8.41 (GPIO29_ADC3)
/MCU/QSPI_CLK: U8.52 (QSPI_SCLK), U9.6 (CLK)
/MCU/QSPI_CS: R28.1, R39.2, U8.56 (QSPI_SS), U9.1 (~CS)
/MCU/QSPI_IO0: U8.53 (QSPI_SD0), U9.5 (DI/IO_{0})
/MCU/QSPI_IO1: U8.55 (QSPI_SD1), U9.2 (DO/IO_{1})
/MCU/QSPI_IO2: U8.54 (QSPI_SD2), U9.3 (~WP/IO_{2})
/MCU/QSPI_IO3: U8.51 (QSPI_SD3), U9.7 (~HOLD/~RESET/IO_{3})
/MCU/SPI_MISO: J8.8, TP7.1, U8.18 (GPIO15)
/MCU/SPI_MOSI: J8.7, TP6.1, U8.15 (GPIO12)
/MCU/SPI_SCK: J8.6, TP5.1, U8.13 (GPIO10)
/MCU/SWDCLK: TP1.1, U8.24 (SWCLK)
/MCU/SWDIO: TP2.1, U8.25 (SWD)
/MCU/USB_N: R30.1; also elsewhere on the board
/MCU/USB_P: R29.1; also elsewhere on the board
/MCU/XTAL_IN: C39.2, U8.20 (XIN), Y1.1
/MCU/XTAL_OUT: R40.1, U8.21 (XOUT)
/MCU/gp_led0: D12.2 (A), U8.37 (GPIO25)
/MCU/gp_led1: D13.2 (A), U8.38 (GPIO26_ADC0)
/MCU/gp_led2: D14.2 (A), U8.39 (GPIO27_ADC1)
/MCU/~RESET: J8.4, R27.2, S1.2_1, S1.2_2, TP8.1, U8.26 (RUN)
/MCU/~SPI_CS: J8.5, TP4.1, U8.16 (GPIO13)
GND: C27.2, C28.2, C29.2, C30.2, C31.2, C32.2, C33.2, C34.2, C35.2, C36.2, C37.2, C38.2, C39.1, C40.2, J8.3, R31.2, R32.2, R33.2, R38.1, S1.1_1, S1.1_2, S2.1_1, S2.1_2, TP3.1, TP32.1, TP33.1, U8.19 (TESTEN), U8.57 (GND), U9.4 (GND), Y1.2, Y1.4; also elsewhere on the board
unnamed: C40.1, R40.2, Y1.3
unnamed: D12.1 (K), R31.1
unnamed: D13.1 (K), R32.1
unnamed: D14.1 (K), R33.1
unnamed: R28.2, S2.2_1, S2.2_2
unnamed: R35.1, R36.2
unnamed: R36.1, R37.2
unnamed: R30.2, U8.46 (USB_DM)
unnamed: R29.2, U8.47 (USB_DP)
unnamed: C27.1, C28.1, C29.1, U8.23 (DVDD), U8.45 (VREG_VOUT), U8.50 (DVDD)

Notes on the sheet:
Other models ok as long as QSPI is supported
SYNC is disconnected by default Drive low when not in use
Driving line low causes RP2040 to enter a reset state.
Test Points (Data)
Driving line low during boot sequence causes RP2040 to boot from USB.
Place physically close to RP2040
Input voltage range: 0 - 250V (max) R1 = 240k R2 = 1.96k (R2 * 250)/(R1 + R2) ≈ 2.025 V RP2040 ADC has 2048 taps LSB ≈ 0.001611 V (ideal) 250/(2.025/0.001611) ≈ 0.1988 V (HV) / LSB
Three LEDs to be used for debugging
Debug Buttons
Place physically close to RP2040 to maintain signal integrity
C11,C13 close to pins 44,45
XTAL tuned to 10p: We assume 3p trace capacitance (15p * 15p)/(15p + 15p) = 7.5p 7.5p + 3p = 10.5p ≈ 10p
R21,R22 close to pins 46,47
Data Connector
Test Points (Gnd)
General-Purpose Indicator LEDs
RP2040 MCU + Support Circuitry
MISO = TX MOSI = RX
External Vcc
High Voltage Sense Line
We don't need these to be very bright Assume 2 V drop @ 1 mA per LED ΔV = IR R = ΔV/I R = (1.3 V)/(1 mA) R = 1.3 kΩ We're bumping it to 1.6 kΩ to further reduce power draw
Drive LOW for USB FLOAT for flash
Design referenced from: https://datasheets.raspberrypi.com/rp2040/hardware-design-with-rp2040.pdf
16 MB External SPI Flash
12 MHz Crystal


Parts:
C6: 10n; C_0603_1608Metric
C7, C9: 22n; C_0603_1608Metric
C8: 100p; C_0603_1608Metric
C10, C11: 10u; C_0603_1608Metric
C12: 0.1uF 50V; C_1206_3216Metric; Manufacturer P/N CL10B104KB8NNWC
C13, C14: 10u 50V; C_1206_3216Metric
C15: 47u 50V; CP_Elec_10x10; Manufacturer P/N PCR1J470MCL1GS
D4: ER3M; D_SMC; Manufacturer P/N ER3M
D5: SBR1U150SA-13; D_SMA; Manufacturer P/N SBR1U150SA-13
Q2: SIR880BDPT1RE3; TRANS_SIR880BDPT1RE3; Manufacturer P/N SIR880BDPT1RE3
R5: 4.7; R_0603_1608Metric
R6: 22; R_0603_1608Metric
R7: 22m 7W; R_2512_6332Metric_Pad1.40x3.35mm_HandSolder; Manufacturer P/N GMR100HJBFIR022
R8: 0; R_0603_1608Metric
R9: 442k; R_0603_1608Metric
R10: 6.8k; R_0603_1608Metric
R11, R12, R13: 100k; R_0603_1608Metric
R14: 10k; R_0603_1608Metric
R15: 40k; R_0603_1608Metric
R16: 1.96k; R_0603_1608Metric
R17: 4.22k 1W; R_2512_6332Metric; Manufacturer P/N CRCW25124K22FKEG; DigiKey P/N 541-4.22KAFCT-ND
R34: 0; R_0603_1608Metric; not fitted
T1: 750032052; WE-FB3751_EFD20; Manufacturer P/N 750032052
TP25: HV_FBK; TestPoint_Pad_D1.0mm
TP26: ~{HV_SHUTDOWN}; TestPoint_Pad_D1.0mm
TP27: HV_SYNC; TestPoint_Pad_D1.0mm
TP28: HV; TestPoint_Pad_D1.0mm
TP29: HV_GND; TestPoint_Pad_D1.0mm
U5: LT3757AEMSE; MSOP-10-1EP_3x3mm_P0.5mm_EP1.68x1.88mm; Manufacturer P/N LT3757AEMSE

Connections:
+BATT: C12.1, C13.1, C14.1, C15.1, R12.2, R17.1, T1.4, T1.5, U5.10 (VIN); also elsewhere on the board
/Capacitor Bank/HV: D4.2 (K), R11.2, TP28.1; also elsewhere on the board
/HV Flyback/DRAIN: D5.2 (A), Q2.D, T1.6, T1.7
/HV Flyback/FEEDBACK: R15.1, R16.2, TP25.1, U5.2 (FBX)
/HV Flyback/INTVCC: C10.1, C11.1, U5.8 (INTVCC)
/HV Flyback/SENSE: C6.1, R6.1, U5.6 (SENSE)
/HV Flyback/SOURCE: Q2.1, Q2.2, Q2.3, R6.2, R7.1
/HV Flyback/SYNC: R34.1; also elsewhere on the board
/HV Flyback/~SHUTDOWN: R12.1, R14.2, TP26.1, U5.9 (~SHDN/UVLO); also elsewhere on the board
GND: C6.2, C7.2, C8.2, C9.2, C10.2, C11.2, C13.2, C14.2, C15.2, R7.2, R8.2, R9.2, R14.1, R16.1, T1.10, TP29.1, U5.11 (GND); also elsewhere on the board
unnamed: C9.1, R10.2
unnamed: D4.1 (A), T1.1
unnamed: C12.2, D5.1 (K), R17.2
unnamed: Q2.4, R5.2
unnamed: R11.1, R13.2
unnamed: R13.1, R15.2
unnamed: R5.1, U5.7 (GATE)
unnamed: R9.1, U5.4 (RT)
unnamed: C7.1, U5.3 (SS)
unnamed: R8.1, R34.2, TP27.1, U5.5 (SYNC)
unnamed: C8.1, R10.1, U5.1 (VC)

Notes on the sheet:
Place MLCC (10uF) caps close to Vin pin.
Feedback Voltage Divider
INTVCC Decoupling
Place caps close to INTVcc
Polymer cap (47uF) near transformer
VIN Decoupling
UVLO Set
442k pull-down on RT sets oscillator frequency at 50k Populate jumper to tie SYNC to ground if not used.
RCD Snubber
Use combination of MLCC and polymer capacitors. Polymer capacitor serves as bulk decoupling. MLCC is high frequency decoupling.
Res should be dissipating abt 1/4 W
Target voltage dropped from 250V to 200V because Cap voltage dropped from 350V to 250V
Components connected to V_{C} pin are part of the LT3757's loop compensation network. The capacitor voltage raises proportionally with (but is not equal to) V_{out}. Once the capacitor charges to 1.78 V, the loop compensation feature stops.
Max sense voltage is 110mV at room temp. RC filter reduces peak voltage on sense pin. Otherwise, current oscillations through primary winding will show up on sense pin and in turn lead to a lower than intended peak primary winding current.
From sim... V_{sn} = 17.75 V dV_{sn} = 890 mV (5% of V_{sn}) V_{in(max)} = 22 V V_{d(rvsmax)} = V_{sn}+V_{in(max)} = 40 V
V_{out} = 1.6*(R2/R1) = 1.6*240kOhm/1.96kOhm ~ 200V
INTVcc is supplied from V_{in} but still requires its own bypass capacitors.
RCD snubber clamps MOSFET drain voltage. When diode become forward biased, capacitor charges, and resistor dissipates energy. RCD as opposed to RC allows lower Vds, thus we can select MOSFET with lower Rdson


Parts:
J9: BB_TX; JST_PH_S3B-PH-K_1x03_P2.00mm_Horizontal
J10: BB_RX; JST_PH_S2B-PH-K_1x02_P2.00mm_Horizontal
Q7: DMG1012T; SOT-523; Manufacturer P/N DMG1012T
R47, R49: 100; R_0603_1608Metric
R48: 10k; R_0603_1608Metric
TP10: BB_SENSE; TestPoint_Pad_D1.0mm
TP11: GND; TestPoint_Pad_D1.0mm
TP12: BB_TRIGGER; TestPoint_Pad_D1.0mm
TP34: BB_DRAIN; TestPoint_Pad_D1.0mm
TP35: BB_SOURCE; TestPoint_Pad_D1.0mm

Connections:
+3.3V: R47.2, R48.2; also elsewhere on the board
/Breakbeam/BB_SENSE: J10.1, R48.1, TP10.1; also elsewhere on the board
/Breakbeam/BB_TRIGGER: R49.2, TP12.1; also elsewhere on the board
GND: J10.2, Q7.2 (S), TP11.1; also elsewhere on the board
unnamed: J9.1, J9.3, Q7.3 (D), TP34.1
unnamed: J9.2, R47.1, TP35.1
unnamed: Q7.1 (G), R49.1

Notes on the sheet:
Breakbeam Recieve
Breakbeam Transmit

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

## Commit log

2019-01-23 Revert "Merge branch 'master' into kicker-v3.1"
    This reverts commit c23d4a97e6f6c85f03ce890f070dcdd2b1e03647, reversing
    changes made to 37001bc4abacc0999c384b25d5227ad49485efd4.
    [breakbeam-v1.0.brd, breakbeam-v1.0.sch]
2019-01-23 Revert "Merge branch 'master' into kicker-v3.1"
    This reverts commit f03af36dfc7d7db138ea10db320d63ba4157f66b, reversing
    changes made to d0f2cc046ed08d33328a71f0e08fc499da8e2f00.
    [breakbeam-v1.0.brd, breakbeam-v1.0.sch]
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2019-01-23 Revert "Changed TVS Diode"
    This reverts commit 328d69bed7fbbd8db63af0c2fca4ca0fd81473df.
    [kicker.brd, kicker.sch]
2019-01-23 Revert "Changed TVS Diode"
    This reverts commit 859410941ee6306b805c1c3f21250df0eea6f1d1.
    [kicker.brd, kicker.sch]
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2019-01-23 Revert "Merge branch 'kicker-v3.1' of https://github.com/RoboJackets/robocup-pcb into kicker-v3.1"
    This reverts commit 68dc4f0d1eb17cedf284ded3c70d9478d43a06bf, reversing
    changes made to ef3dfebe4da0a04fef4c75c46becc354c3ef985d.
    [kicker.brd, kicker.sch]
2019-01-23 Revert "Merge branch 'kicker-v3.1' of https://github.com/RoboJackets/robocup-pcb into kicker-v3.1"
    This reverts commit 3f9aa72e8fafa28a2d49236f807afbdfeaaf371e, reversing
    changes made to c50544483e11115e4d784ecccb4640d13441df38.
    [kicker.brd, kicker.sch]
2019-01-23 Minor Fixes
    [kicker.brd, kicker.sch]
2019-01-27 Routing/TVS Snubber Fixes
    [kicker.brd, kicker.sch]
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2019-02-03 Added more tvs diodes and caps
    Needs to be routed and checked
    [kicker.brd, kicker.sch]
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2019-02-08 replaced 5v buck, added FB resistor divider, more routing
    [kicker.brd, kicker.sch]
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2019-02-11 Fixes to J5, ball/charge LEDs, routing
    [kicker.brd, kicker.sch]
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2019-02-17 Fixed some wire stubs
    [control.brd]
2019-02-18 Fixed a footprint for IC
    [control.brd, control.sch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]
2019-02-18 updated numbering, design review fixes
    [radio-v3.0.brd, radio-v3.0.sch]
2019-02-19 Update schematic
    -organized decoupling banks for LT3751
    -moved LT3751 control and ESD to new page
    -moved kick/chip to new page
    -added current limiting resistors to SPI lines to stop leakage
    -added optional capacitor to TVS-RCD snubber on switching FET source
    [kicker.brd, kicker.sch]
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2019-02-27 routing finished, silkscreen fixes
    [kicker.brd, kicker.sch]
2019-03-01 added TVS, cleaned silkscreen, passing EuroCircuit C6-18 DRU
    [kicker.brd, kicker.sch]
2019-03-04 lots of routing cleanup, passign EuroCircuite EC-18C DRC
    [kicker.brd]
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2019-04-20 Changed to different caps, changed to TI ldos since the other ones are out of stock, and changed some label positions
    [control.brd, control.sch]
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2019-07-03 Merged new boards and moved old boards to archive
    [base-station.brd, base-station.sch, breakbeam-v1.0.brd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]
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2019-07-18 Removed SPI Isolator and Rotating Kicker and changed SBs by 0 ohms on SCH
    [control.brd, control.sch]
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2019-08-04 fix capacitive coupling at the FB shunt
    [kicker.brd, kicker.dxf, kicker.sch]
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2019-08-25 fixed connector library
2019-08-25 Fixed a bunch of random things, before changing VBatt layer
    [control.brd, control.sch]
2019-08-25 Separated VBatt layer into 18.5V polygon and VBatt polygon, still need to make sure polygons are in good place
    [control.brd]
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2019-09-01 kicker dr fixes
    [kicker.brd, kicker.sch]
2019-09-02 passing core fixes
    [kicker.brd, kicker.sch]
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2019-09-02 fixed frames
    [kicker.sch]
2019-09-02 final fixes and docs
    [kicker.brd, kicker.sch]
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2019-09-02 Fixed RST network
    [control.brd, control.sch]
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2019-09-06 reset FET fixes
    [control.brd, control.sch]
2019-09-08 Fixed labeling of reset network wires, added via for 1.2V, fixed silkscreen overlap
    [control.brd, control.sch]
2019-09-08 Fixed schematic for IMU
    [control.brd, control.sch]
2019-09-08 fixed IMU decoupling
    [control.brd, control.sch]
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2019-09-24 Post-order minor fixes
    [control.brd, control.sch]
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2019-10-09 Moved old radio board to archive and put new radio board in folder
    [radio-v3.0.brd, radio-v3.0.sch, radio-v3.0_centroid.csv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]
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2019-10-09 Changed layout to improve routing and component placement, still plenty of improvements that can be made
    [radio-v3.1.brd, radio-v3.1.sch]
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2019-10-09 Changed some routing by making 5V wider at pins, added vias for all gnd vias, made sure gnd plane can get to all caps
    [radio-v3.1.brd, radio-v3.1.sch]
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2019-11-19 More IMU board fixes
    [LSM9DS1-breakout.brd, LSM9DS1-breakout.sch]
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2019-11-28 Fixed error in ICM 42605 circuit
    [ICM-42605-breakout.brd, ICM-42605-breakout.sch, LSM9DS1-breakout.brd]
2019-11-28 Fixed board and text for ICM 42605
    [ICM-42605-breakout.brd, ICM-42605-breakout.sch, LSM9DS1-breakout.brd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]
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2019-12-04 Ball Speed Routing
    Routed the board file for the ball speed sensor and corrected some errors in the schematic.
    [ballspeed-v1.0.brd, ballspeed-v1.0.sch]
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2020-03-07 More fixes to Kicker V3.2.1
    See clickup for up-to-date changes
    [kicker.brd, kicker.sch]
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2020-03-10 Kicker v.3.2.1, Checked, Signed-Off
    DRC: eC-Default-2layer
    - 17 clearance errors - all pad spacing on LT*
    - overriden/approved
    - added TX silkscreen
    - added RX silkscreen
    - added PWR silkscreen
    [kicker.brd]
2020-03-10 More silkscreen changes to account for MFG view
    Kicker ID, R30, R31, R41, C20, C24, C25, C23, J7, J8, J9, HV AC near D2. J4. J5, R42, C35, D6, R3, R4. Q5
    Silkscreen on wrong layer were fixed
    SFW8 Part connector added (not used yet)
    [kicker.brd]
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2020-05-11 Fixed incorrect number in control schematic
    [control.sch]
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2020-05-12 Adjused radio, kicker, and radio file names, as well as frames to have versioN
    [breakbeam.brd, breakbeam.sch, kicker.brd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]
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2020-05-14 Fixed PMOD connector orientation, updated mtrain part to have silkscreen, and updated board
    [trinamicboard.brd, trinamicboard.sch]
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2020-05-16 Added bottom SPI connections to board Changed position of buffers Changed position of connectors
    [trinamicboard.brd, trinamicboard.sch]
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2020-05-18 Updated Capacitor library to have missing capacitor from control
    [control.brd]
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2020-05-18 Fixed spelling errors
    [breakbeam.sch, control.sch, radio.sch]
2020-05-18 Fixed versioning on breakout boards
    [ICM-20948-breakout.brd, ICM-20948-breakout.sch, ICM-42605-breakout.brd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]
2020-05-18 Added missing connector from breakbeam to connectors library
    [breakbeam.brd, breakbeam.sch]
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2020-05-19 Fixed motor tester issues
    [motortester.brd, motortester.sch]
2020-05-19 Fixed ICM breakout to remove sparkfun references
    [ICM-20948-breakout.brd, ICM-20948-breakout.sch]
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2020-05-23 Changed ADC/TMCs, PMODs/TMCs bottom traces Fixed routing issues
    [trinamicboard.brd]
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2020-05-24 Fixed net naming issue
    [trinamicboard.brd, trinamicboard.sch]
2020-05-26 Fixed ERC/DRC issues
    [trinamicboard.brd, trinamicboard.sch]
2020-05-26 Fixed trace sizing, but have clearance issues
    [trinamicboard.brd]
2020-05-26 Fixed 190 clearance issues
    [trinamicboard.brd]
2020-05-30 Added mouting holes Added silkscreen details Modified TMCs footprint to add tPlace layer
    [trinamicboard.brd, trinamicboard.sch]
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2020-06-07 Fixed variant name and footprint name
2020-06-08 Redesign to suit control imu breakout kit Major changes to icm 20948 breakout: removed mTrain added imu breakout kit updated schematics finish placing/wiring in board Minor changes to icm 20948 devic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
    [ICM-20948-breakout.brd, ICM-20948-breakout.sch]
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2020-06-15 Expanded board size Added decaupling capacitors Added resistor for EO in level shifter
    [ICM-20948-breakout-v2.0.brd, ICM-20948-breakout-v2.0.sch]
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2020-06-20 Removed some bottom traces in icm board. Added top traces. Expanded size to left and right .1 mm. Changes to icm-20948 footprint.
    [ICM-20948-breakout-v2.0.brd]
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2020-06-21 Minor stylistic fixes
    [trinamicboard.sch]
2020-06-21 Fixed vector font
    [trinamicboard.brd]
2020-06-21 Fixed last silkscreen to vector
    [trinamicboard.brd]
2020-06-21 Fixed silkscreen and mounting hole size/posistion
    [trinamicboard.brd, trinamicboard.sch]
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2020-06-25 Made boards consistent on Eagle
    Made board and schematic on Eagle consistent
    [VL6180X Design.brd, VL6180X Design.sch]
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2020-06-28 Fixed extra files that shouldn't be here
    [ICM-20948-breakout-v2.0.brd, ICM-20948-breakout-v2.0.sch]
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2020-06-28 Fixed git file locations and version
    [ICM-20948-breakout.brd, ICM-20948-breakout.sch]
2020-06-28 Made board 4 layer and fixed some routing issues
    [trinamicboard.brd]
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2020-06-29 Started fixing routing issues
    [trinamicboard.brd, trinamicboard.sch]
2020-07-08 minor changes on IR board
    grid and added one more sensor and changed header (connector)
    [VL6180X Design.brd, VL6180X Design.sch]
2020-08-05 Fixed trinamic per design review
    [trinamicboard.brd]
2020-08-05 Added initial set of fixes recommended by Arthur
    [trinamicboard.brd, trinamicboard.sch]
2020-08-05 Fixed silkscreen alignment
    [trinamicboard.brd]
2020-08-05 Attempted fix of analog signal routing
    [trinamicboard.brd, trinamicboard.sch]
2020-08-05 Continued fix of analog signal routing
    [trinamicboard.brd]
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2020-08-06 Fixed further issues with GND planes and spacing
    [trinamicboard.brd]
2020-08-07 Finished minor revisions fixing trace spacing and soldermask openings
    [trinamicboard.brd]
2020-08-07 Fixed issues with traces crossing layers
    [trinamicboard.brd]
2020-08-09 Fixed traces too close to switch
    [trinamicboard.brd]
2020-08-09 Fixed minor schematic/routing issues, adjusted 18.5V circuitry
    [trinamicboard.brd, trinamicboard.sch]
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2020-08-10 Fixed wirestub
    [trinamicboard.brd]
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2020-08-24 Fixed review changes
    [ICM-20948-breakout.brd, ICM-20948-breakout.sch]
2020-08-25 Fix dimension
    [VL6180X Design.brd, VL6180X Design.csv]
2020-08-27 Fixed dimensions
    [VL6180X Design.brd]
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2020-10-18 Stepper Motor Supply Correction
    fixed stepper motor supply (5.0V --> 3.3V); added nets from stepper motor driver to 4pin connecter (represents stepper motor)
    [StepperMotorDrive_mbed.sch]
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2020-11-07 Swapped to horizontal connector + increased size of roboBuzz
    [StepperMotorDriver_MTrain.brd, StepperMotorDriver_MTrain.sch]
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2020-11-07 Aesthetic Updates
    Updated DRV footprint, added frame to mbed schematic, added ID and title to boards
    [StepperMotorDriver_MTrain.brd, StepperMotorDriver_MTrain.sch, StepperMotorDriver_mbed.brd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]
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2021-02-09 Fixed info layer on sch
    [breakbeam.brd, breakbeam.sch]
2021-04-25 schematic changes
    added decoupling capacitors to MUX & color sensors, value to capacitors on LDO, changed connector order.
    [robotshellid.brd, robotshellid.sch]
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2021-05-12 Organized Schematic and Layout
    I reorganized the schematic and rerouted some parts of the brd per recommendations. To do: Ground Plane & routing new schematic parts
    [robotshellid.brd, robotshellid.sch]
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2021-12-19 QoL changes
    Moved dot stars, removed dip switch, added vertical ffc connector for control->radio, changed kicker connector for non obsolete part, changed out df22 battery connector for xt60 battery connector
    [control.brd, control.sch]
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2021-12-28 Replaced J3 with a vertical FFC connector
    [control.brd, control.sch]
2021-12-29 Fixed routing for radio and i2c connections
    [control.brd, control.sch]
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2022-01-11 Moved radio to control connector
    Rerouted connector pins, slightly changed board dimensions
    [radio.brd, radio.sch]
2022-01-11 Revert "Moved radio to control connector"
    This reverts commit 1f2474f5bc392d319ce3634a53d5999081512a16.
    [radio.brd, radio.sch]
2022-01-11 Revert "Moved radio to control connector"
    This reverts commit 5c6b5c88ba9a94fd72d2333e45117e65158598a8.
    [radio.brd, radio.sch]
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2022-01-17 Replaced 220uF Capacitor (on Schematic)
    [radio.brd, radio.sch]
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2022-02-02 Add files via upload
    Made the board a trapezoid shape after the first design review (Jan 2022).
    [robotshellid_trapezoid.brd]
2022-02-02 Made changes after design review
    See Breakbeam Design Review document (1/22/22) for specific changes made
    [breakbreamRx-v1.0.brd, breakbreamRx-v1.0.sch]
2022-02-07 Partial design review fixes
    [control.brd, control.sch]
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2022-02-12 Revert "new connectors"
    This reverts commit 2318692ef87a26a7dfbf2da43cca6fa2515fe9a6.
    [control.brd, control.sch]
2022-02-12 Revert "new connectors"
    This reverts commit d26c4569cc8482982f596aa44375689ecdd3de69.
    [control.brd, control.sch]
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2022-02-12 removed reset network
    [control.brd, control.sch]
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2022-02-16 Changed to correct LED
    [breakbeamTx-v1.0.brd, breakbeamTx-v1.0.sch]
2022-02-16 Changed to correct diode
    [breakbreamRx-v1.0.brd, breakbreamRx-v1.0.sch]
2022-02-21 Design Review Fixes
    Fixed the comments from the design review on 02/12/22
    [ICM-42688-breakout.brd, ICM-42688-breakout.sch, LSM9DS1-breakout_newest.brd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]
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2022-02-26 silkscreen fixes and trace widening
    [breakbeamTx-v1.0.brd, breakbreamRx-v1.0.brd, breakbreamRx-v1.0.sch]
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2022-02-27 Swapped i2c and radio locations
    [control.brd]
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2022-08-02 Readme (#51)
    * created a readme file for boards
    * Added intro for the doc & few headers
    * Create breakbeam-v1.1
    * Delete breakbeam-v1.1
    * Reorganizing to on-robot and off-robot
    * Create README.md
    [ICM-20948-breakout.brd, ICM-20948-breakout.sch, ICM-42605-breakout.brd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]
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2022-08-06 Kicker v4.0 (#59)
    * start of 4.0
    * Library update and DRC update
    * Work in progress
    * Consistency improving
    * more fixes
    * Consistent
    * Fixed buttons
    * Pot moved
    * More fixes
    * Moved solenoid connectors
    * Replaced power connectors
    * Repalced breakbeam connector
    * Changed SFW8R-1STE1LF for SFW8S-2STE1LF
    * Silkscreen fixes
    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
    [kicker.brd, kicker.sch]
2022-08-06 Control again (#60)
    * Adjustments
    * work
    * Changes
    * Work
    * Fixes
    * added connectors
    * pain
    * Control has a mouth
    * Made connectors actually good
    * Connectors connecting yeah
    * Added shell outline
    * Fixes
    * One side completed
    * I hate eagle
    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
    [control.brd, control.sch]
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2022-08-06 Control v4.0 Radio Backwards compatibility connector change (#61)
    * control changes
    * radio backward compatibility connection changes
    [control.brd, control.sch]
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2023-01-30 Changed size of LED vias and another LED symbol (#64)
    * Changed size of LED vias and another LED symbol
    * Revisioned board
    ---------
    [breakbeamTx-v1.1.brd, breakbeamTx-v1.1.sch]
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2023-02-01 Fixed Breakbeam RX width and reverted back to old TX (#66)
    * Fixed Breakbeam RX width and reverted back to old TX
    * Removed bbtx-v1.0 from archive
    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
    [breakbeamTx-v1.0.brd, breakbeamTx-v1.0.sch, breakbreamRx-v1.0.brd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]
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2023-04-19 Fixed J3 Connector
    [control.brd, control.sch]
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2024-02-26 New Folder Created Created BreakBeam-rx (#69)
    * Create control-v4.0-2024-02-25_200843.zip
    * Copied and Renmaed Breakbeamrx files
    [breakbeamrx-v2.0.kicad_pcb, breakbeamrx-v2.0.kicad_sch]
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2024-02-28 Initial RJ KiCad Lirabries (#71)
    * added iniitial library files and tested importing from EAGLE
    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
    [Breakbeam.kicad_sch, HV_-_Auto_Discharge.kicad_sch, HV_-_Control_&_Bypass.kicad_sch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]
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2024-07-15 found flipped LED silkcreen
    [kicker-tester-v1.0.kicad_pcb, kicker-tester-v1.0.kicad_sch, motortester-v2.0.kicad_pcb]
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2024-09-04 Revert my previous commit
    [power.kicad_sch]
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2024-09-16 Finished fixing global labels, LED indicator for MCU
    [motor.kicad_sch, motorboard-v1.0.kicad_sch]
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2024-09-23 Added correct motor connectors
    [motor.kicad_sch, motorboard-v1.0.kicad_sch]
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2024-09-29 Added correct motor connectors and made control connections
    [motor.kicad_sch, motorboard-v1.0.kicad_sch]
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2024-10-07 Fixed typo on label
    [motorboard-v1.0.kicad_sch]
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2024-10-21 Swapped XT-60 connector, added prog LED
    [motor.kicad_sch, motorboard-v1.0.kicad_sch]
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2025-02-17 added debug connector to access control signals coming from control board (3v3_en, diag_en, sns, int, kill) :
    [dribbler.kicad_sch, motor.kicad_sch, motorboard-v1.0.kicad_pcb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]
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2025-04-12 fixed initial motor test bugs
    [dribbler.kicad_sch, motor.kicad_sch, motorboard-v1.0.kicad_pcb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]
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2025-09-29 Move control-test-board into reworked repo (#74)
    * Restrcutured files and added manufacturing data (#67)
    * added kicad directories for upcoming projects (#68)
    * New Folder Created Created BreakBeam-rx (#69)
    * Added kicad lib (#70)
    * Initial RJ KiCad Lirabries (#71)
    * started design and updated readme
    * most of the design is done
    * teensy_adapter_board v3 and finished c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
    [BSD_rev_1.brd, BSD_rev_1.sch, Breakbeam.kicad_sch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]
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2026-02-07 fixed? motorboard
    [dribbler.kicad_sch, motor.kicad_sch, motorboard-v1.0.kicad_pcb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]
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2026-02-07 fixed silkscreen
    [motorboard-v1.0.kicad_pcb]
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2026-04-08 fixed more mitsakes
    [dribbler.kicad_sch, motorboard-v1.0.kicad_pcb]
2026-04-10 bump KiCAD version to 10, fix lib paths
    [dribbler.kicad_sch, motor.kicad_sch, motorboard-v1.0.kicad_pcb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]
2026-04-10 fixed the motorboard final v2
    [dribbler.kicad_sch, motor.kicad_sch, motorboard-v1.0.kicad_pcb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]
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2026-05-03 fix pcb formatting
    [breakout-AS5047P.kicad_pcb]
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2026-07-16 Resolve all ERC, tweak formatting
    [enc_sense.kicad_sch, ext_conn.kicad_sch, integration-test.kicad_pcb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]
2026-08-21 tweak issues found during review, prep for single-shunt current sense
    [ext_conn.kicad_sch, motor_controller.kicad_sch, power.kicad_sch]
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2026-09-18 Fix SWD pinout mistake
    [ext_conn.kicad_sch, integration-test.kicad_pcb, motor_controller.kicad_sch]
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

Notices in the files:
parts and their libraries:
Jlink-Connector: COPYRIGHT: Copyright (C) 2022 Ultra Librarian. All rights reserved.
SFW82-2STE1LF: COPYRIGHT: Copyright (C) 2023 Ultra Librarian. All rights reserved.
